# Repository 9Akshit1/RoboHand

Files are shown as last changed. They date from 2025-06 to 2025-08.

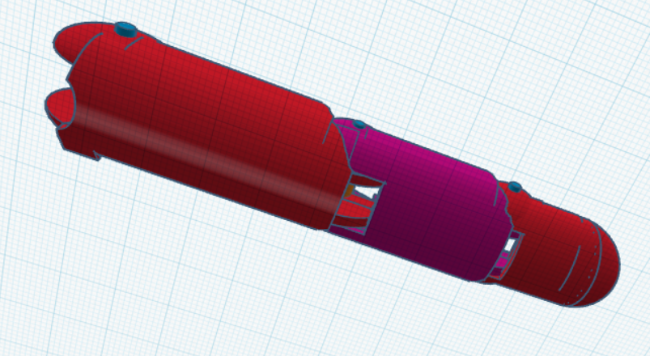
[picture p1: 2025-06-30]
assets/CAD_j28_pic2.png

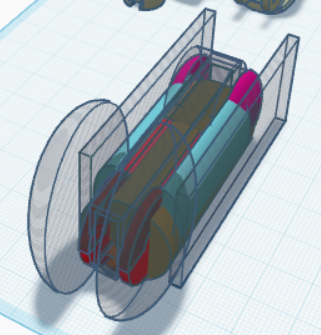
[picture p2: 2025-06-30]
assets/cad_before.png

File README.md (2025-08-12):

# RoboHand
DESCRIPTION: RoboHand is just like how it sounds. It is a robotic hand with five fingers that can mimic real hand movements. It uses small servo motors controlled by a smart camera board to copy gestures like fists or peace signs. The hand can also be controlled manually via a computer or preset motions for easy testing and flexibility.

INSPIRATION: I've always been inspired by how human hands move and wanted to recreate that motion using motors and tendons. Additionally, at the same time, I was learning how to simulate robots in physics based simulations called MuJoCo, which is why I wanted to also actaully build a hand and test my inverse kinematics coding knowledge at it.

Note: I am currently working on polishing the CAD, so it's much thinner, models the human hand better, and allows for full movement!

# Final CAD
The separate finger files and body files are in ther CAD folder. The full built hand CAD File is called RoboHand.stl in the CAD folder. 

The below five images are each finger's separated pieces. They are all essentially copies of the Middle_Finger.stl file, except they have been scaled to be shorter. 

Also, please note that I can always just add supports before I 3D print, so we do not need to worry about that!

Middle Finger (the original finger):

Final CAD Middle Finger Separated

Thumb Finger (a scaled down version of the middle finger):

Final CAD Thumb Finger Separated

Index Finger (a scaled down version of the middle finger):

Final CAD Index Finger Separated

Ring Finger (a scaled down version of the middle finger):

Final CAD Ring Finger Separated

Pinky Finger (a scaled down version of the middle finger):

Final CAD Pinky Finger Separated

Also, note that for the below hand-body/palm separated image, none of the parts are touching but they are very close to each other. That is just temporary. When I actually 3D print everything, I will separate those parts into different CAD files.

Final CAD Body Separated

This is what the full build hand will look like. I will likely hot glue every piece together. 

Final CAD Frontside

Final CAD Backside

Final CAD Underside

# Final Circuit Schematic
Schematic is called robohand.kicad_sch in the schematic_pcb/robohand folder. While this shows 4 EMG sensors (the ESP32-CAM doesnt have enough pins), I actually need 9 EMG sensors to fluidly control a human hand and train it to be extremely good at autonomous imitation. Since the ESP32-CAM doesn't have enough pins, I decided to use the board setup I will be getting from my RoboArm project. That project has enough pins for me to connect all of my EMG sensors. 

Final Schematic

# Final Firmware Stuff
The firmware software is in the firmware folder, and are called esp32_ver.py (which will be used on the ESP32-CAM board), and pc_ver.py (which can be tested on a PC).

Camera Tracking UI Full Hand Open

Camera Tracking UI Spider Man Pose

## Bill of Materials (BOM)

| Item | Quantity | Total Cost (USD) | Description / Part Number | Notes | Links |
|---|---|---|---|---|---|
| **ESP32-CAM module** | 1 | $9.04 | ESP32-CAM Module | Main controller + camera | https://www.aliexpress.com/item/1005006341099716.html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 |
| **ESP32-CAM DEV Board** | 1 | $2.08 | ESP32-CAM DEV Board | Needed to actualyl conenct ESP32 and program it | https://www.aliexpress.com/item/1005006341099716.html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 |
| **MG90S Servo Motor** | 10 | $20.99 | Metal Gear Micro Servo, 9g | Cheapest price servo motor. Need 3 for thumb, because it has that many DOF and each of those are important. We have 4 motors for the lower section's movement of the other fingers. Ideally, I wouldve wanted another 4 more motors so I could control the middle section's movement of the other fingers, but the aliexpress link only allows me to buy 3 more, so I'll need to buy another one on my own later. In the CAD, 5 can be seen directly, but there will actually be 6 more contained within the hand and the arm to controll all of my DOF. | https://www.aliexpress.com/item/1005008626768357.html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 |
| **Electrolytic Capacitor 1000µF, 10V** | 1 | $3.21 | Radial leaded capacitor | Power filtering. The link has 10 pcs but there was no other product that only sold 1 piece and this was the cheapest  | https://www.aliexpress.com/item/33010665515.html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 |
| **Male/Female Jumper Wires** | ~15 | N/A| Dupont cables (already owned) | For wiring servos, buttons, ESP32 | N/A |
| **Female Power Adapter DC Barrel to Screw Plug Jack Connector** | 1 | $2.52 | Mr.Geeker 10 Pcs Female Power Adapter DC Barrel to Screw Plug Jack Connector 2.1x5.5mm | Used to connect the power adapter to the ESP32-CAM board but manage the power and GND. The product link was the cheapest deal I could find | https://www.aliexpress.com/item/1005008987005268.html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 |
| **EMG Sensors** | Muscle BioAmp Candy | 9 | $89.91 | Muscle activity sensors. These are one of the best quality sensors suitable for research projects such as this and are also the cheapest deal I found everywhere! I need 9 because I'm doing a full hand, where each finger has around 2 DOF, except the thumb which has 3 and the pinky which I decided to let it have only 1 EMG since its muscles are highly connected with the other fingers. | https://www.tindie.com/products/upsidedownlabs/muscle-bioamp-candy-emg-sensor/ |
| **ADC Modules** | ADS1115 | 1 | $1.97 | 16-bit ADC | https://www.aliexpress.com/item/1005007628692389.html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 |

**BOM Cost:** $129.72 USD ≈ $176.73 CAD            

**Shipping:** $14.91 USD ≈ $20.31 CAD     --- The cost comes from the EMG sensors. Everything else is FREE SHIPPING becuase this will be my frist ever order on Aliexpress

**Taxes (in  Ontario, Canada, it's 13%):** $18.80 USD ≈ $25.62 CAD

**Total Cost:** $163.43 USD ≈ $222.66 CAD

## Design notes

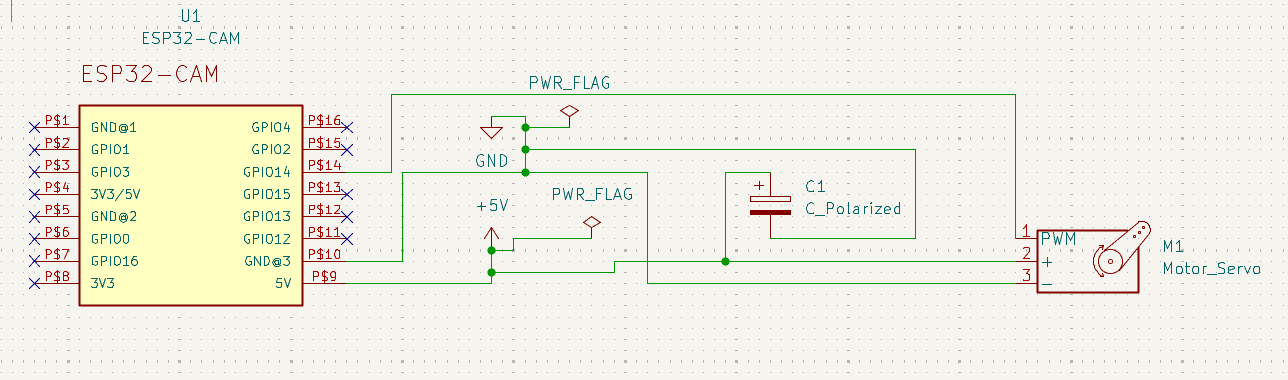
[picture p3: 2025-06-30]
assets/schematic_j30.png

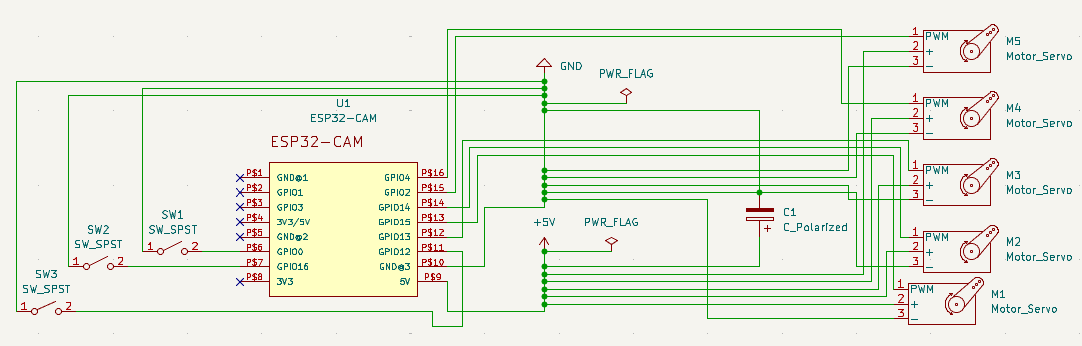
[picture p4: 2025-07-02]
assets/schematic_jy2.png

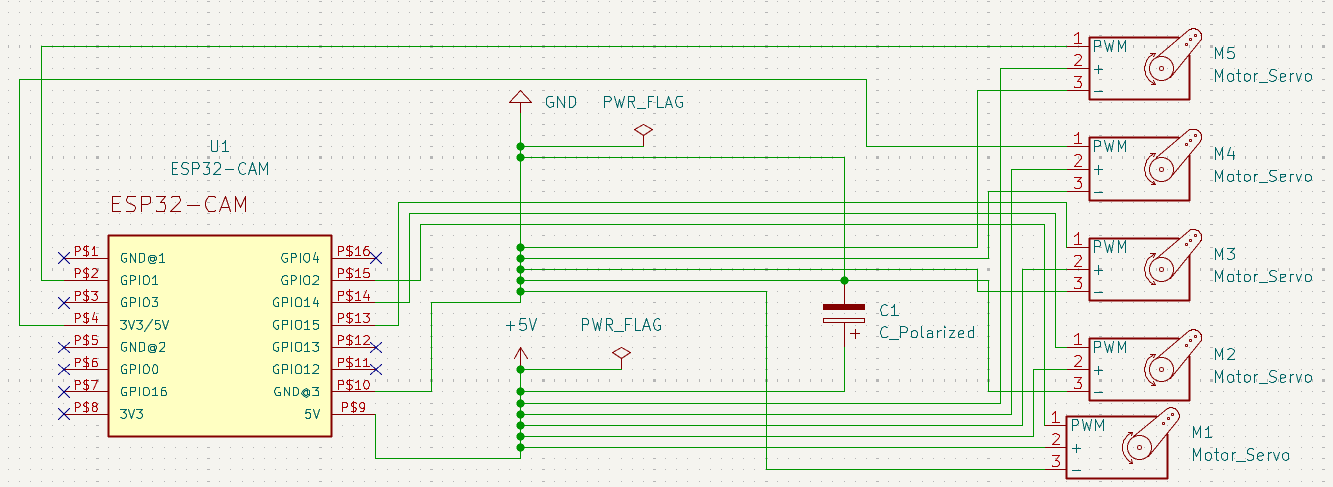
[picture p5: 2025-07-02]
assets/schematic_jy1.png

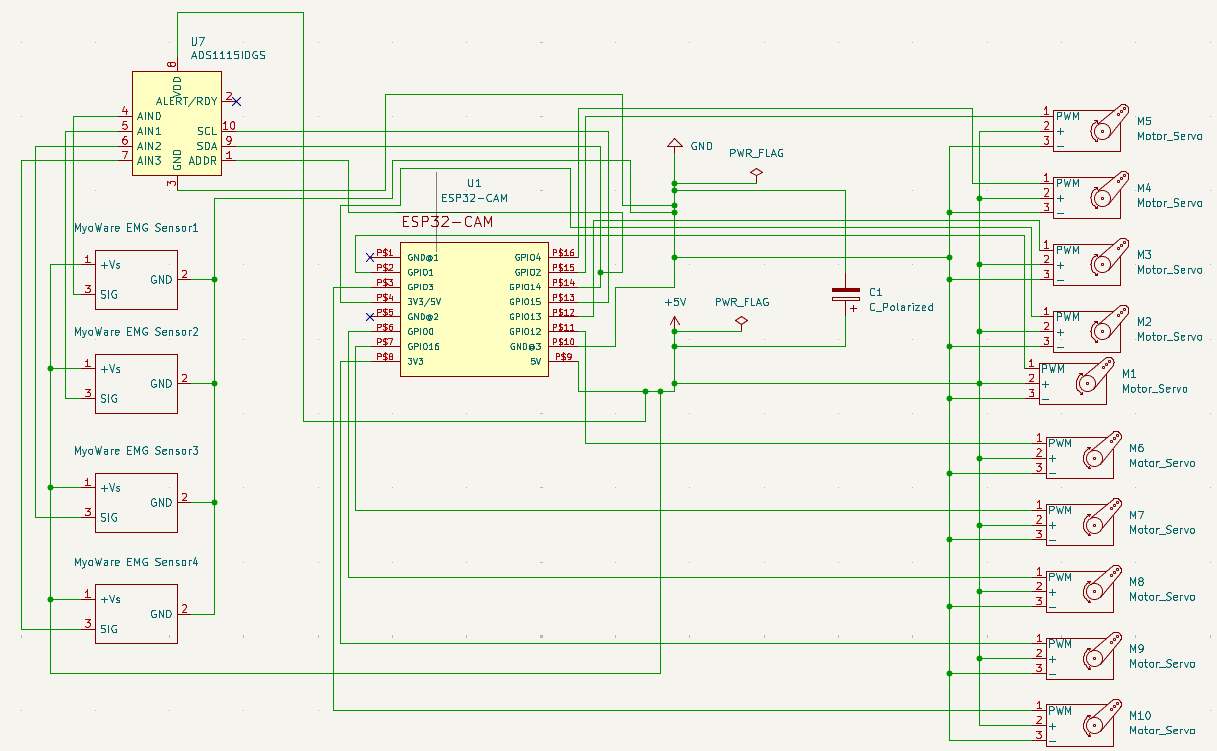
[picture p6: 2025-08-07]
assets/schematic_au6.png

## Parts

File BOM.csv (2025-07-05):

Item | Quantity | Total Cost (USD) | Description / Part Number | Notes | Links
ESP32-CAM module | 1 | $18.72 | AI-Thinker ESP32-CAM Dev Board | Main controller + camera | https://www.amazon.ca/YTHYTHYTH-ESP32-CAM-Camera-Module-Development/dp/B0CPYHC78H
MG90S Servo Motor | 5 | $13.84 | Metal Gear Micro Servo, 9g | One per finger | https://www.amazon.ca/MG90S-MG-90S-Servo-Motor-Micro/dp/B0C6XSLBHT
Pushbutton Switch (NO, SPST) | 3 | $7.35 | Mini tactile pushbutton switch | For mode selection buttons. The link is the cheapest one (in terms of price per piece) I could find including the shipping (since its in Canada where I live) | https://www.amazon.ca/uxcell-6x6x5mm-Terminals-Button-Switch/dp/B07JM27QJC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
Electrolytic Capacitor 1000µF, 10V | 1 | $7.35 | Radial leaded capacitor | Power smoothing for servo supply. The cheapest version is in the link (20 pieces), because buying singular ones are extremely expensive due to shipping | https://www.amazon.ca/uxcell-1000uF-Radial-Electrolytic-Capacitor/dp/B016EK6H9M
USB 5V 3A DC–DC Converter | 1 | $8.24 | USB Power Adapter | Powers servos and ESP32 | https://www.amazon.ca/G120503-Converter-Waterproof-Convertor-Navigation/dp/B0D2RGT8SW
Male/Female Jumper Wires | ~15 | Already Owned | Dupont cables | For wiring servos, buttons, ESP32 | N/A
USB to Serial Adapter (FTDI) | 1 | $6.48 | For programming ESP32-CAM | ESP32-CAM has built-in USB, but I do not have this, which is why I need it | https://www.amazon.ca/Adapter-Performance-Communication-Devices-Plastic/dp/B0F7QXZ8RD
3D Printed Parts (CAD) | Varies | $5.00 - $20.00 | Finger joints, palm base, mounts (~75g PLA) | Varies by the estimated filament cost and the number of trials of testing | N/A
3 Pin JST-XH Connector (20 pieces) | 1 | $6.78 | 20 Sets Pack Micro JST 1.25MM 3 Pin Male Female Connector Plug with Wires Cables | Need this to coneect the servo motors and the V+s and the GNDs | https://www.amazon.ca/1-25MM-Female-Connector-Cables-Circuit/dp/B0DDJSTVWX?s=industrial
3‑Pin Header (2.54 mm) | 1 | $5.14 | Chanzon Pin Header Strip for Arduino Gpio 3 pin x 50pcs Female Headers Pins Straight Single Row Gold Plated Pitch 2.54mm | Need this to connect the servo motors and the V+s and the GNDs. The link is the best deal even though it has 50pcs | https://www.amazon.ca/Chanzon-Straight-Connector-Breadboard-Electronic/dp/B09MYMD4YS
Female Power Adapter DC Barrel to Screw Plug Jack Connector | 1 | $7.36 | Mr.Geeker 10 Pcs Female Power Adapter DC Barrel to Screw Plug Jack Connector 2.1x5.5mm | Used to connect the power adapter to the ESP32-CAM board but manage the power and GND. The product link was the cheapest deal I could find | https://www.amazon.ca/dp/B00NXGVWIM

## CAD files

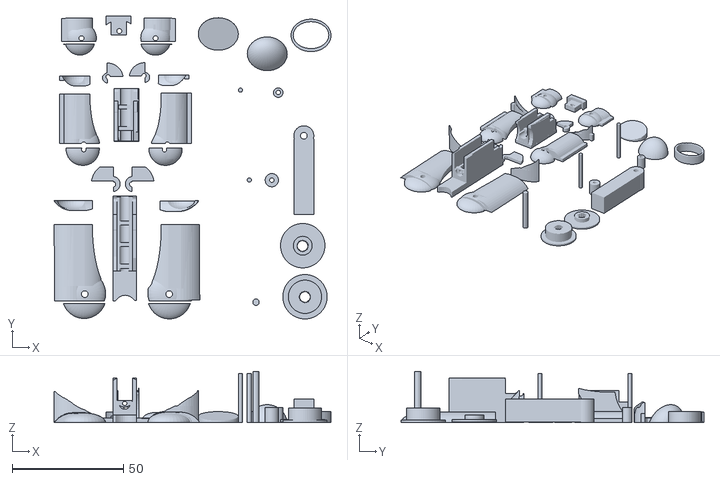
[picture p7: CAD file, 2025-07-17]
CAD/Middle_Finger.stl
124.7 x 136.4 x 23.0

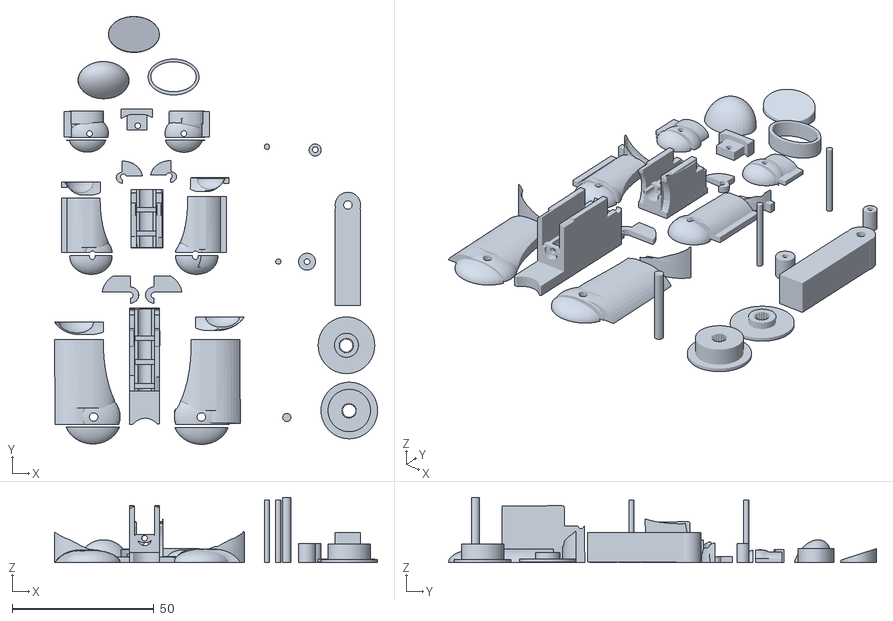
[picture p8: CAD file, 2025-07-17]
CAD/Thumb_Finger.stl
114.1 x 151.0 x 23.0

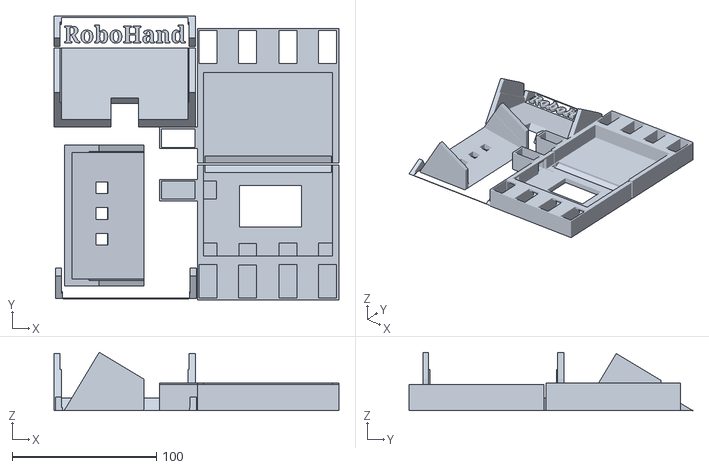
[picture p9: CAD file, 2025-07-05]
CAD/Body_RoboHand.stl
197.5 x 197.1 x 40.6

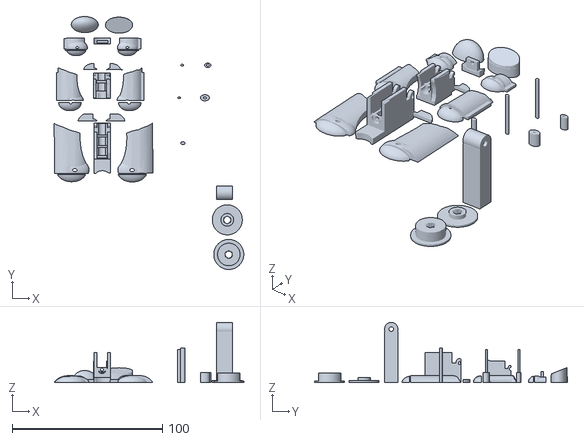
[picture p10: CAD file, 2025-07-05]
CAD/Pinky_Finger.stl
126.1 x 168.1 x 40.0

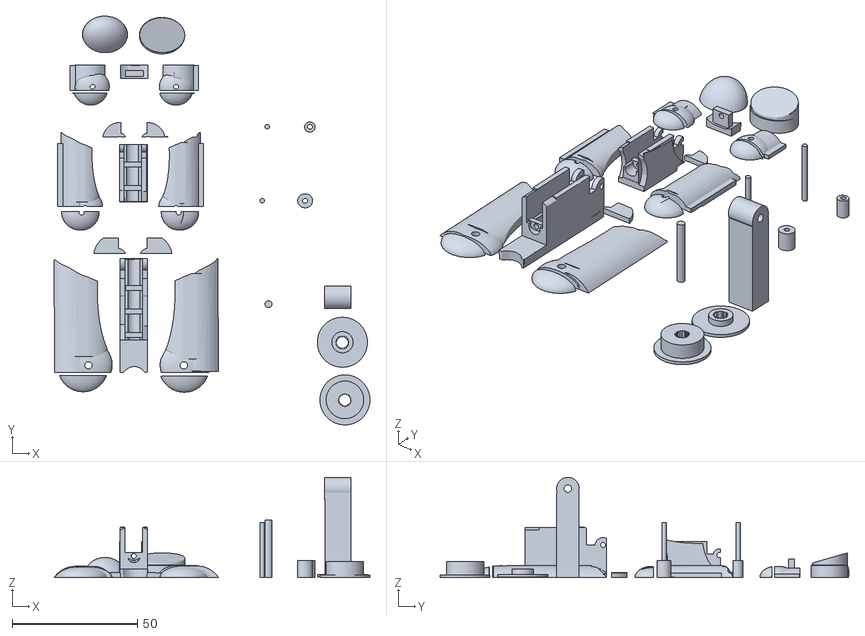
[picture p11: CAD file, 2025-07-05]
CAD/Ring_Finger.stl
126.1 x 163.1 x 40.0

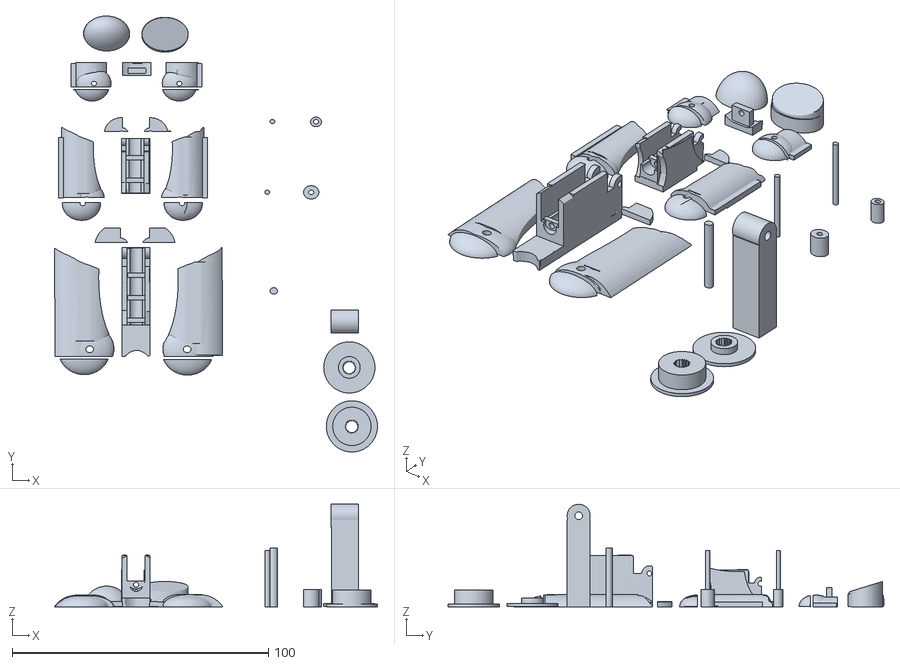
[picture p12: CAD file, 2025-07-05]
CAD/Index_Finger.stl
126.1 x 170.1 x 40.0

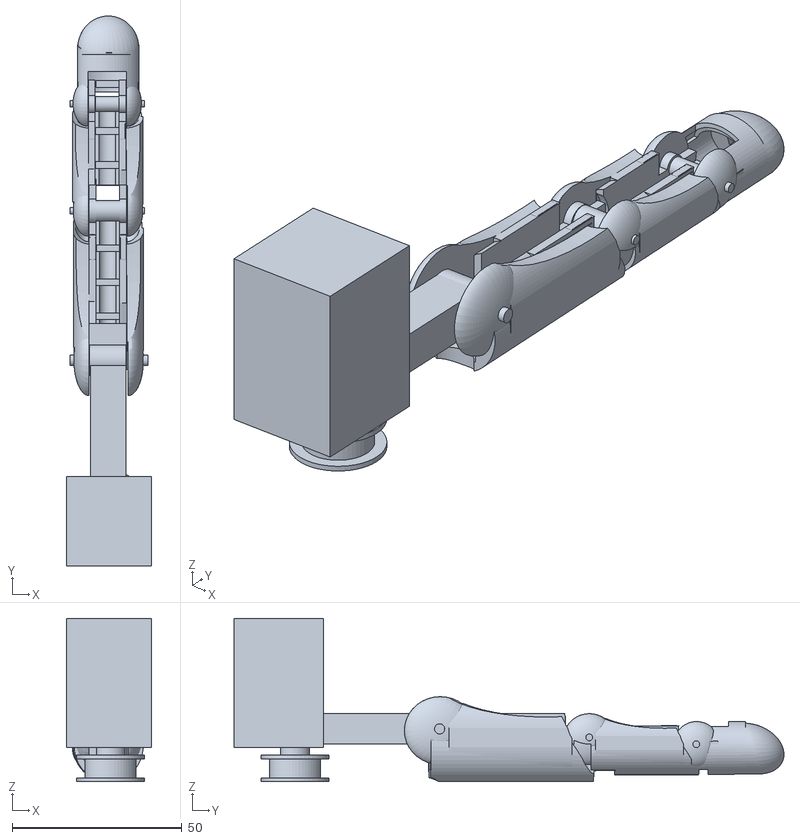
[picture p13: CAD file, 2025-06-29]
CAD/Robo-Finger.stl
25.0 x 161.8 x 48.0

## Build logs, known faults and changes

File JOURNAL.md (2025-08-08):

---
title: "RoboHand"
author: "Akshit Erukulla"
description: "A robotic finger has 2–3 hinged segments moved by servos or tendons, controlled by a microcontroller and powered by a battery."
created_at: "2025-06-26"
---
**Total Time spent: 23h**

# June 26th:
I worked on my CAD. I had to really think about how to design the finger. I decided to start off with some cylidners and then processeded to hollow them out, cut them, connect them, then add the plates with holes for a string (kevlar line) to go through all the fingers, so it can pull and curl the fingers.
I planned how I was going to design the whole finger and motion (sideways, and curling motion). I decided to use a string to curl the finger, by making a motor pull the string. For sideways movement, I will just use a servo motor probably.

CAD Finger

**Time spent: 1.5h**

# June 27th:
I completely changed my cad and tried to model an actual finger. I found a reference iamge so I worked off based off of that. This took a lot of tiem because I had to also develop parts for the bendable parts fo the finger. I had to use many different shapes and in the images atached, there should be one that shows how many different shapes I had to carefully plan out.

CAD Finger Part Before

CAD Finger Parts Lined Up

**Time spent: 3.5h**

# June 28th:
I finished my CAD I think. I addee the hinges, I added the holes/guides for the kevlar string. I also added the holes for where I would connect the finger parts, and designed the tubes I need for that.

CAD Finger Whole Frontside

CAD Finger Whole Backside

**Time spent: 3.5h**

# June 29th:
I just added the servo motor holder (it took some time designing the holder for the servo motor accurately and also its axle's shape stuff) and the spool I will need to the CAD. For my final CAD file, I will take the stuff apart and put them separate so that the 3D printer can actually properly 3D print stuff.

CAD Finger Whole

**Time spent: 1.5h**

# June 30th:
I designed the schematic for my robot finger/hand. I decided that all I will need is an ESP32-CAM module and a servo motor. So, I added those (it took some time to also add the symbol libraries and footprints too). I also realized I needed to add a capacitor as well. After runnign ERC, I received a few errors, so I fixed the unconnected pins with a No Connect end, and then also added the PWR_FLAGs. I was originally going to design a PCB too, but I realized that since it's just one finger, and also there may be some errors and refinning and testing and stuff, a PCB would take too long to make each time.

Schematic

**Time spent: 1.5h**

# July 1st:
I decided that although starting with one finger is probably good for testing and refining, I should still design the whole hand. So, for the CAD, I duplicated the figners and shrotened their lengths. Then I made the palm body and the base prism body to hold up the whole thing. Similarily, I changed the circuit schematic to incldue all 5 servo motors. I realized that I will also likely need to have a stronger 1000 µF capcitor probably. Next time, I will start working on the firmware coding, which will be complex since I need to code using the camera for hand + finger tracking.

CAD Full Hand

Schematic Full Hand

**Time spent: 2h**

# July 2nd:
While I was coding, I realized I wanted 3 buttons to switch between different modes for the arm (hand tracking, computer command based, or preset gestures). So, I added the holes for the button in the CAD, then added the 3 buttons to my circuit schematic. After that, I designed my PCB. I'm likely not going to use a PCB when I build it just becauseits faster for testing if I don't, however, since the PCB looks nice and lcean, I just designed it too. I also worked on my BOM and README file.
Finally, I worked on coding my software for this. I had to design the OpenCV code and make it compatible with teh ESP32-CAM. I had to also code the commands of the servo motor control which was much easier than I thought it would be since it  is just setting angles, however, the calculations were very difficult to figure out and I had to use online sources. I had to also code internal pull-up resistors for the button because I was suggested by a friend to do that just to ensure stability. I learned quite a lot about the circuit schematics today as well, because I realized I hasd messed up my connections for everything, since I was just connecting based on the pin name, and not the GPIO number. I'm not done yet, but I am almost done.

CAD Full Hand Frontside

CAD Full Hand Backside

CAD Full Hand Underside

Schematic Full Hand with Buttons

PCB Full Hand with Buttons

**Time spent: 3h**

# July 3rd:
While I was working on my BOM, I realzied that I will need a Female Power Adapter DC Barrel to Screw Plug Jack Connector, so I added that and also made a hole for it in my CAD. I also continued working on my coding. I actually used mediapipe such that the finger tracking would work this time compared to yesterday. I used a tutorial for this, since I am a beginner with mediapipe. I also had to follow a tutorial on how to use pyserial which took some time. The hardest part was converting the code to the esp32_version because I couldn't even test that python file. I also preprogrammed the different gestures which was actually pretty easy after I got the camera tracking thing working. I just copied the angles from there. I applied some error handling so that since I do not have the ESP32-CAM with me for testing right now, it would jsut print what signals or servo angles it would send.

CAD Full Hand Backside

Camera Tracking UI Full Hand Open

Camera Tracking UI Spider Man Pose

**Time spent: 2.5h**

# July 4th:
Before I submitted my project, I remembered that my original CAD file would get rejected because it was the fully built hand, however, in an actual 3D printer, everything would have to be separate and proper so there are no floating parts. So, it took me a long time making sure each part was separated into valid 3D printable parts. I had to take out all the hinges, the axles, the sides of the fingers, split part the body boxes, and more. I made sure that everything was not floating and would properly print. Also, note that for the body separated image, none of the parts are touching but they are very close to each other. That is just temporary. When I actually 3D print everything, I will separate those parts into different CAD files. This was a very time consuming and precise process.

Final CAD Thumb Finger Separated

Final CAD Index Finger Separated

Final CAD Middle Finger Separated

Final CAD Ring Finger Separated

Final CAD Pinky Finger Separated

Final CAD Body Separated

**Time spent: 3h**

# August 6th:
I changed the schematic because I realized I could fit in some EMG sensors, since I wanted to shift this project to a more mind-controlled robotic hand to make it more unique. So, I changed the circuit schematic and the BOM. It took some time figuring out how to fix the schematic though. I think the CAD is fine since I can put the motors within the hand and the arm. I also was able to find cheaper EMG sensors and so I updated the BOM. I did find a cheaper EMG sensor, but they only ship to India, so I emailed them and am waiting on a response.

Final Schematic

**Time spent: 1h**

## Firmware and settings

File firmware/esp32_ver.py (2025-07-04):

"""
Real-time Hand Tracking for ESP32-CAM Robotic Hand Controller
Uses MediaPipe Hands to track finger positions and calculate bend angles.
Sends servo control commands via serial to ESP32-CAM controller.

Requirements:
pip install opencv-python mediapipe pyserial numpy

Hardware Setup:
- ESP32-CAM with 5 servo motors connected
- USB connection to computer for serial communication
- Webcam for hand tracking

Author: AI Assistant
"""

import cv2
import mediapipe as mp
import numpy as np
import serial
import time
import math
from collections import deque
import sys

# Configuration
SERIAL_PORT = '/dev/ttyUSB0'  # Change to 'COM3' on Windows
SERIAL_BAUDRATE = 115200
SEND_INTERVAL = 0.15  # Send data every 150ms
SMOOTHING_WINDOW = 5  # Moving average window size

# MediaPipe configuration
mp_hands = mp.solutions.hands
mp_drawing = mp.solutions.drawing_utils
mp_drawing_styles = mp.solutions.drawing_styles

# Finger landmark indices for MediaPipe Hands
FINGER_LANDMARKS = {
    'thumb': [1, 2, 3, 4],      # CMC, MCP, IP, TIP
    'index': [5, 6, 7, 8],      # MCP, PIP, DIP, TIP
    'middle': [9, 10, 11, 12],  # MCP, PIP, DIP, TIP
    'ring': [13, 14, 15, 16],   # MCP, PIP, DIP, TIP
    'pinky': [17, 18, 19, 20]   # MCP, PIP, DIP, TIP
}

class AngleFilter:
    """Smooths angle values using moving average"""
    
    def __init__(self, window_size=5):
        self.window_size = window_size
        self.values = deque(maxlen=window_size)
    
    def update(self, value):
        """Add new value and return smoothed result"""
        self.values.append(value)
        return sum(self.values) / len(self.values)
    
    def reset(self):
        """Clear the filter"""
        self.values.clear()

class HandTracker:
    """Real-time hand tracking and finger angle calculation"""
    
    def __init__(self, serial_port=SERIAL_PORT, baudrate=SERIAL_BAUDRATE):
        # Initialize MediaPipe Hands
        self.hands = mp_hands.Hands(
            static_image_mode=False,
            max_num_hands=1,
            min_detection_confidence=0.7,
            min_tracking_confidence=0.5
        )
        
        # Initialize serial connection
        self.serial_connection = None
        self.init_serial(serial_port, baudrate)
        
        # Initialize angle filters for each finger
        self.angle_filters = {
            'thumb': AngleFilter(SMOOTHING_WINDOW),
            'index': AngleFilter(SMOOTHING_WINDOW),
            'middle': AngleFilter(SMOOTHING_WINDOW),
            'ring': AngleFilter(SMOOTHING_WINDOW),
            'pinky': AngleFilter(SMOOTHING_WINDOW)
        }
        
        # Store previous angles for fallback
        self.previous_angles = [90, 90, 90, 90, 90]  # Default middle position
        self.last_send_time = time.time()
        
        # Calibration parameters (adjust these for better accuracy)
        self.calibration = {
            'thumb': {'min_angle': 20, 'max_angle': 160},
            'index': {'min_angle': 10, 'max_angle': 170},
            'middle': {'min_angle': 10, 'max_angle': 170},
            'ring': {'min_angle': 15, 'max_angle': 165},
            'pinky': {'min_angle': 20, 'max_angle': 160}
        }
        
        print("Hand Tracker initialized!")
        print(f"Serial port: {serial_port}")
        print("Press 'q' to quit, 'r' to reset filters")
    
    def init_serial(self, port, baudrate):
        """Initialize serial connection to ESP32-CAM"""
        try:
            self.serial_connection = serial.Serial(port, baudrate, timeout=1)
            time.sleep(2)  # Wait for connection to establish
            print(f"Serial connection established on {port}")
        except Exception as e:
            print(f"Warning: Could not establish serial connection: {e}")
            print("Running in display-only mode")
    
    def calculate_angle(self, p1, p2, p3):
        """
        Calculate angle between three points (p1-p2-p3)
        Returns angle in degrees (0-180)
        """
        # Convert to numpy arrays
        p1, p2, p3 = np.array(p1), np.array(p2), np.array(p3)
        
        # Calculate vectors
        v1 = p1 - p2
        v2 = p3 - p2
        
        # Calculate angle using dot product
        cos_angle = np.dot(v1, v2) / (np.linalg.norm(v1) * np.linalg.norm(v2))
        cos_angle = np.clip(cos_angle, -1, 1)  # Ensure valid range
        angle = math.degrees(math.acos(cos_angle))
        
        return angle
    
    def get_finger_angle(self, landmarks, finger_name):
        """
        Calculate bend angle for a specific finger
        Returns angle in 0-180 range (0=curled, 180=straight)
        """
        finger_points = FINGER_LANDMARKS[finger_name]
        
        if finger_name == 'thumb':
            # For thumb, use different calculation due to its unique movement
            # Use CMC-MCP-IP points
            p1 = [landmarks[finger_points[0]].x, landmarks[finger_points[0]].y]
            p2 = [landmarks[finger_points[1]].x, landmarks[finger_points[1]].y]
            p3 = [landmarks[finger_points[2]].x, landmarks[finger_points[2]].y]
        else:
            # For other fingers, use MCP-PIP-DIP points
            p1 = [landmarks[finger_points[0]].x, landmarks[finger_points[0]].y]
            p2 = [landmarks[finger_points[1]].x, landmarks[finger_points[1]].y]
            p3 = [landmarks[finger_points[2]].x, landmarks[finger_points[2]].y]
        
        # Calculate raw angle
        raw_angle = self.calculate_angle(p1, p2, p3)
        
        # Apply calibration mapping
        cal = self.calibration[finger_name]
        
        # Map raw angle to 0-180 range
        # Smaller joint angles typically mean more curled fingers
        if raw_angle < cal['min_angle']:
            mapped_angle = 0
        elif raw_angle > cal['max_angle']:
            mapped_angle = 180
        else:
            # Linear mapping
            mapped_angle = ((raw_angle - cal['min_angle']) / 
                          (cal['max_angle'] - cal['min_angle'])) * 180
        
        return int(mapped_angle)
    
    def process_hand_landmarks(self, landmarks):
        """Process hand landmarks and return finger angles"""
        finger_angles = []
        finger_names = ['thumb', 'index', 'middle', 'ring', 'pinky']
        
        for finger_name in finger_names:
            # Calculate raw angle
            raw_angle = self.get_finger_angle(landmarks, finger_name)
            
            # Apply smoothing filter
            smoothed_angle = self.angle_filters[finger_name].update(raw_angle)
            
            # Clamp to valid range
            smoothed_angle = max(0, min(180, int(smoothed_angle)))
            finger_angles.append(smoothed_angle)
        
        return finger_angles
    
    def send_to_robot(self, angles):
        """Send angle data to ESP32-CAM via serial"""
        if self.serial_connection and self.serial_connection.is_open:
            try:
                # Format command for ESP32-CAM
                command = f"MIMIC {','.join(map(str, angles))}\n"
                self.serial_connection.write(command.encode())
                print(f"Sent: {command.strip()}")
            except Exception as e:
                print(f"Serial send error: {e}")
        else:
            print(f"No serial connection - would send: {angles}")
    
    def draw_finger_info(self, image, angles, landmarks=None):
        """Draw finger angle information on the image"""
        finger_names = ['Thumb', 'Index', 'Middle', 'Ring', 'Pinky']
        
        # Draw angle information
        y_offset = 30
        for i, (name, angle) in enumerate(zip(finger_names, angles)):
            color = (0, 255, 0) if angle > 90 else (0, 255, 255)  # Green if extended, yellow if curled
            cv2.putText(image, f"{name}: {angle}°", (10, y_offset + i * 25),
                       cv2.FONT_HERSHEY_SIMPLEX, 0.6, color, 2)
        
        # Draw connection status
        status_color = (0, 255, 0) if (self.serial_connection and 
                                     self.serial_connection.is_open) else (0, 0, 255)
        status_text = "Serial: Connected" if (self.serial_connection and 
                                            self.serial_connection.is_open) else "Serial: Disconnected"
        cv2.putText(image, status_text, (10, image.shape[0] - 20),
                   cv2.FONT_HERSHEY_SIMPLEX, 0.6, status_color, 2)
        
        # Draw hand landmarks if available
        if landmarks:
            mp_drawing.draw_landmarks(
                image, landmarks, mp_hands.HAND_CONNECTIONS,
                mp_drawing_styles.get_default_hand_landmarks_style(),
                mp_drawing_styles.get_default_hand_connections_style())
    
    def run(self):
        """Main tracking loop"""
        cap = cv2.VideoCapture(0)
        
        if not cap.isOpened():
            print("Error: Could not open camera")
            return
        
        # Set camera resolution
        cap.set(cv2.CAP_PROP_FRAME_WIDTH, 640)
        cap.set(cv2.CAP_PROP_FRAME_HEIGHT, 480)
        
        print("Starting hand tracking...")
        print("Controls:")
        print("  'q' - Quit")
        print("  'r' - Reset angle filters")
        print("  'c' - Toggle calibration display")
        
        show_calibration = False
        
        while True:
            ret, frame = cap.read()
            if not ret:
                print("Error: Could not read frame")
                break
            
            # Flip frame horizontally for mirror effect
            frame = cv2.flip(frame, 1)
            
            # Convert BGR to RGB
            rgb_frame = cv2.cvtColor(frame, cv2.COLOR_BGR2RGB)
            
            # Process frame with MediaPipe
            results = self.hands.process(rgb_frame)
            
            current_angles = self.previous_angles.copy()  # Fallback to previous
            
            if results.multi_hand_landmarks:
                for hand_landmarks in results.multi_hand_landmarks:
                    # Calculate finger angles
                    current_angles = self.process_hand_landmarks(hand_landmarks.landmark)
                    
                    # Update previous angles
                    self.previous_angles = current_angles
                    
                    # Draw landmarks and info
                    self.draw_finger_info(frame, current_angles, hand_landmarks)
                    
                    break  # Only process first hand
            else:
                # No hand detected - use previous angles
                self.draw_finger_info(frame, current_angles)
                cv2.putText(frame, "No hand detected", (10, 160),
                           cv2.FONT_HERSHEY_SIMPLEX, 0.8, (0, 0, 255), 2)
            
            # Send data at regular intervals
            current_time = time.time()
            if current_time - self.last_send_time >= SEND_INTERVAL:
                self.send_to_robot(current_angles)
                self.last_send_time = current_time
            
            # Show calibration info if requested
            if show_calibration:
                y_pos = 200
                cv2.putText(frame, "Calibration Ranges:", (10, y_pos),
                           cv2.FONT_HERSHEY_SIMPLEX, 0.6, (255, 255, 255), 2)
                for i, (finger, cal) in enumerate(self.calibration.items()):
                    text = f"{finger}: {cal['min_angle']}-{cal['max_angle']}"
                    cv2.putText(frame, text, (10, y_pos + 20 + i * 20),
                               cv2.FONT_HERSHEY_SIMPLEX, 0.5, (255, 255, 255), 1)
            
            # Display frame
            cv2.imshow('Hand Tracking - Robotic Hand Controller', frame)
            
            # Handle key presses
            key = cv2.waitKey(1) & 0xFF
            if key == ord('q'):
                print("Quitting...")
                break
            elif key == ord('r'):
                print("Resetting angle filters...")
                for filter_obj in self.angle_filters.values():
                    filter_obj.reset()
            elif key == ord('c'):
                show_calibration = not show_calibration
                print(f"Calibration display: {'ON' if show_calibration else 'OFF'}")
        
        # Cleanup
        cap.release()
        cv2.destroyAllWindows()
        if self.serial_connection and self.serial_connection.is_open:
            # Send neutral position before closing
            self.send_to_robot([90, 90, 90, 90, 90])
            time.sleep(0.5)
            self.serial_connection.close()
            print("Serial connection closed")

def main():
    """Main function"""
    print("ESP32-CAM Robotic Hand Controller")
    print("=================================")
    
    # Configuration
    serial_port = SERIAL_PORT
    if len(sys.argv) > 1:
        serial_port = sys.argv[1]
        print(f"Using serial port from command line: {serial_port}")
    
    try:
        tracker = HandTracker(serial_port=serial_port)
        tracker.run()
    except KeyboardInterrupt:
        print("\nInterrupted by user")
    except Exception as e:
        print(f"Error: {e}")
    finally:
        print("Hand tracking stopped")

if __name__ == "__main__":
    main()

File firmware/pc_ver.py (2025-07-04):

"""
Real-time Hand Tracking for Robotic Hand Control
PC-side application that tracks human hand movements and sends finger bend angles
to an ESP32-CAM robotic hand via serial communication.

Features:
- Real-time hand tracking using MediaPipe
- Finger bend angle calculation (0-180°)
- Serial communication with ESP32-CAM
- Smoothing filters for stable control
- Visual feedback and debugging overlay
- Auto-detection of serial ports
- Configurable parameters

Requirements:
- opencv-python
- mediapipe
- numpy
- pyserial

Author: AI Assistant
Date: 2025
"""

import cv2
import mediapipe as mp
import numpy as np
import serial
import serial.tools.list_ports
import time
import threading
import queue
from typing import List, Tuple, Optional, Dict
import sys
import math

class AngleFilter:
    """Exponential smoothing filter for angle values"""
    
    def __init__(self, alpha: float = 0.3):
        """
        Initialize filter with smoothing factor
        Args:
            alpha: Smoothing factor (0-1), lower = more smoothing
        """
        self.alpha = alpha
        self.filtered_values = None
        self.initialized = False
    
    def update(self, new_values: List[float]) -> List[float]:
        """
        Update filter with new angle values
        Args:
            new_values: List of 5 finger angles
        Returns:
            Filtered angle values
        """
        if not self.initialized:
            self.filtered_values = new_values.copy()
            self.initialized = True
            return self.filtered_values
        
        # Apply exponential smoothing
        for i in range(len(new_values)):
            self.filtered_values[i] = (self.alpha * new_values[i] + 
                                     (1 - self.alpha) * self.filtered_values[i])
        
        return self.filtered_values.copy()
    
    def reset(self):
        """Reset filter state"""
        self.initialized = False
        self.filtered_values = None

class SerialCommunicator:
    """Handles serial communication with ESP32-CAM"""
    
    def __init__(self, port: str = None, baudrate: int = 115200):
        """
        Initialize serial communicator
        Args:
            port: Serial port name (e.g., 'COM3' or '/dev/ttyUSB0')
            baudrate: Communication speed
        """
        self.port = port
        self.baudrate = baudrate
        self.serial_connection = None
        self.connected = False
        self.command_queue = queue.Queue()
        self.last_send_time = 0
        self.send_interval = 0.15  # 150ms between commands
        
    def list_available_ports(self) -> List[str]:
        """
        List all available serial ports
        Returns:
            List of available port names
        """
        ports = serial.tools.list_ports.comports()
        return [port.device for port in ports]
    
    def connect(self, port: str = None) -> bool:
        """
        Connect to serial port
        Args:
            port: Optional port name override
        Returns:
            True if connection successful
        """
        if port:
            self.port = port
        
        if not self.port:
            print("❌ No serial port specified")
            return False
        
        try:
            self.serial_connection = serial.Serial(
                self.port, 
                self.baudrate, 
                timeout=1
            )
            self.connected = True
            print(f"✅ Connected to {self.port} at {self.baudrate} baud")
            
            # Start communication thread
            self.comm_thread = threading.Thread(
                target=self._communication_loop, 
                daemon=True
            )
            self.comm_thread.start()
            
            return True
            
        except serial.SerialException as e:
            print(f"❌ Failed to connect to {self.port}: {e}")
            return False
    
    def disconnect(self):
        """Disconnect from serial port"""
        if self.serial_connection and self.connected:
            self.connected = False
            self.serial_connection.close()
            print(f"🔌 Disconnected from {self.port}")
    
    def send_angles(self, angles: List[int]) -> bool:
        """
        Send finger angles to ESP32-CAM
        Args:
            angles: List of 5 finger angles (0-180°)
        Returns:
            True if command was queued successfully
        """
        current_time = time.time()
        
        # Rate limiting
        if current_time - self.last_send_time < self.send_interval:
            return False
        
        self.last_send_time = current_time
        
        # Format command
        angle_str = ','.join(map(str, angles))
        command = f"MIMIC {angle_str}"
        
        if self.connected:
            try:
                self.command_queue.put(command, block=False)
                return True
            except queue.Full:
                print("⚠️ Command queue full")
                return False
        else:
            # Print command for debugging when not connected
            print(f"🤖 Would send: {command}")
            return True
    
    def _communication_loop(self):
        """Background thread for serial communication"""
        while self.connected and self.serial_connection:
            try:
                # Send queued commands
                try:
                    command = self.command_queue.get_nowait()
                    self.serial_connection.write(f"{command}\n".encode())
                    print(f"📤 Sent: {command}")
                except queue.Empty:
                    pass
                
                # Read responses (optional)
                if self.serial_connection.in_waiting > 0:
                    response = self.serial_connection.readline().decode().strip()
                    if response:
                        print(f"📥 ESP32: {response}")
                
                time.sleep(0.01)
                
            except Exception as e:
                print(f"❌ Communication error: {e}")
                break
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

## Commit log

2025-06-28 uplaoded the CAD file
    [Robo-Finger.stl]
2025-06-30 schematic done
    [Robo-Finger.stl, robohand.kicad_pcb, robohand.kicad_sch]
2025-07-02 full CAD hand done
    [robohand.kicad_pcb, robohand.kicad_sch]
2025-07-02 july 2nd
    [robohand.kicad_pcb, robohand.kicad_sch]
2025-07-04 july 3rd mainly coding hand tracking firmware
    [BOM.csv, robohand.kicad_pcb, robohand.kicad_sch]
2025-07-05 july 4th mainly CAD fixing
    [BOM.csv, Body_RoboHand.stl, Index_Finger.stl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]
2025-07-17 deleted .3mf file
    [Middle_Finger.3mf, Middle_Finger.stl]
2025-07-26 edited readme and fixed esp32 library issue
    [robohand.kicad_pcb, robohand.kicad_sch]
2025-08-07 august 6th - some schematci and BOM editing
    [robohand.kicad_pcb, robohand.kicad_sch]
